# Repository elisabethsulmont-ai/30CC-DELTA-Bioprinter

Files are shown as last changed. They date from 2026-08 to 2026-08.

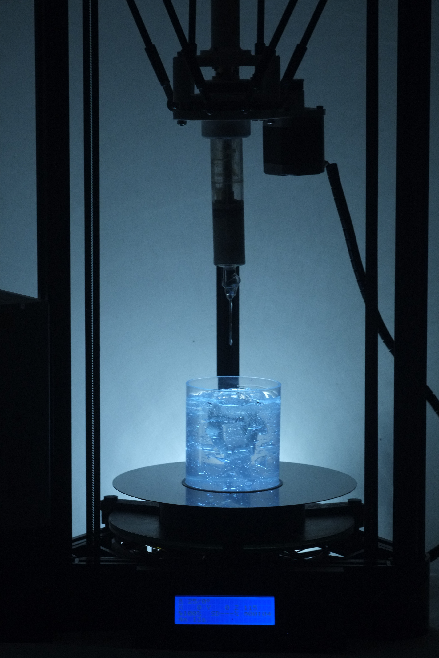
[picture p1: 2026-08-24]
5_PROJET EXAMPLES/DSCF0151.JPG

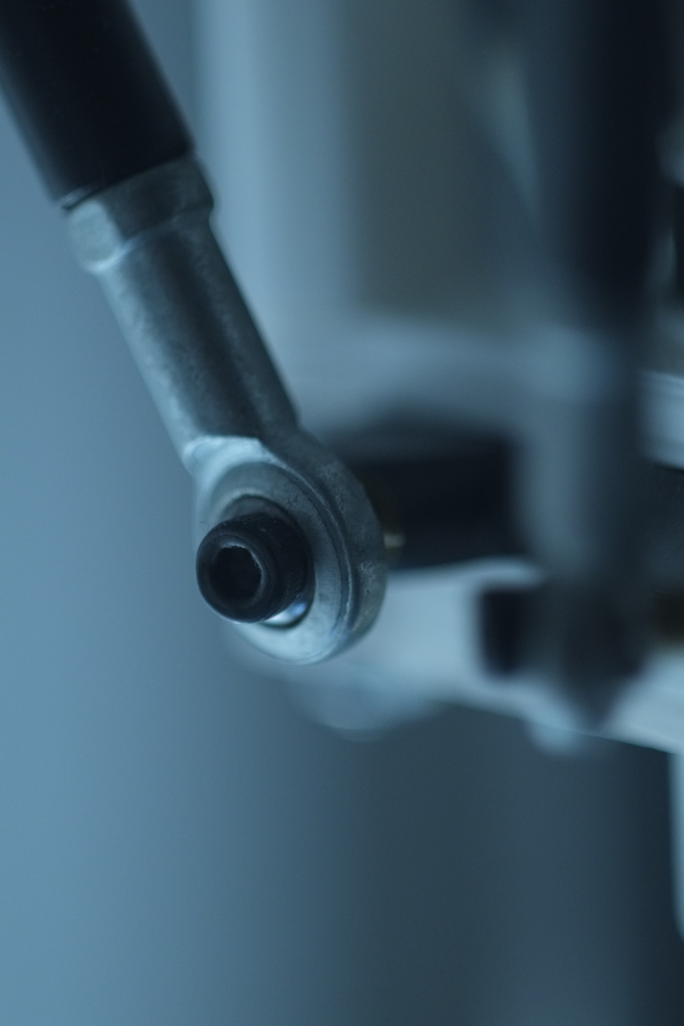
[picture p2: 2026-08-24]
5_PROJET EXAMPLES/DSCF0004.JPG

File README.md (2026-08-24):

# 30CC-DELTA-Bioprinter

An open source syringe bioprinter for the extrusion of viscous biomaterials, developed with
Ilias Poutsiakas ([github.com/iliasPts](https://github.com/iliasPts)).

It is built on an Anycubic Kossel Linear, stripped down to its bare frame and control board.
The hotend and its heating assembly are removed and replaced by a syringe extruder, designed
after the [300CC Extruder](https://www.thingiverse.com/thing:5215048) by Emmanuel Hugnot. The
stock firmware is replaced by an open source one: extrusion rates rescaled for a plunger
instead of a filament drive, travel limits redefined around the syringe, everything tied to
heating the nozzle removed.

The syringe is a 30 cc glass barrel with a metal luer lock, sized for fine biomaterials in
small volumes. Changing the tip is enough to set the flow, which matches the machine to the
viscosity of the material, down to very fluid ones. Tips run from 0.31 to 2.69 mm inner
diameter, 24G to 10G. The extrusion is cold.

A delta can be fed trajectories directly, without going through a conventional slicer: the
G-code can be a continuous path in space rather than a stack of planes. The motors are fixed
to the frame and no axis is privileged, so a curve costs the machine no more than a straight
line and the movement stays fluid. Conventional layer by layer printing works just as well.

The build is inexpensive and every part can be found in a hardware store. The concept is to
make bioprinting accessible outside of laboratories. What the machine makes depends on what
goes in the syringe and on what it prints into. Here it has been used for embedded printing
in a Carbopol support bath, and that method is documented in this repository.

**!!!!!!!!!!!!This is a workshop machine, made for experimental work. It is not a laboratory instrument, it is certified for nothing and it is not intended for any medical use.!!!!!!!!!!!!**

Other than than, Have fun <3

## What is in this repository

| Folder | What's inside |
|---|---|
| `3D files` | Parts to print, and the editable sources to modify them |
| `Components bill` | Everything to buy, with quantities and where to find it |
| `Assembly` | How to build it, step by step, with photos |
| `Firmware_marlin` | The two configuration files, and how to compile them |
| `Project examples` | Projects made with the machine, starting with Liquid Dreaming |

The order to follow: strip the printer down, print the parts from `3D files`, order what is
listed in `Components bill`, build it with `Assembly`, then flash the firmware from
`Firmware_marlin`. Once the machine runs, `Project examples` shows what has been done with it.

DSCF9794-3

DSCF9827-3

___________________________________

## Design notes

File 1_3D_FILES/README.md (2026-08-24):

## Materials

| Part | Material | Why |
|---|---|---|
| All parts | Matte white PLA | rigid enough, and easy to source anywhere |
| Piston | [TPU 95A HF](https://eu.store.bambulab.com/fr/products/tpu-95a-hf) | flexible, so it seals against the syringe wall |

The piston is the only part that is not printed rigid. A rigid piston does not seal: the
paste creeps back up along the barrel wall instead of coming out of the tip. Printed in TPU,
the piston deforms slightly against the glass and acts as its own gasket.

TPU prints slowly and does not tolerate retraction well. Print it with no retraction, at low
speed, and with a direct drive extruder if you have one.

<!-- TODO : tes réglages réels pour le piston. Le taux de remplissage et le nombre de parois
     comptent beaucoup ici, puisque c'est l'étanchéité qui est en jeu. -->

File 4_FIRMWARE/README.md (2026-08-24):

# Firmware

This machine runs a modified configuration of Marlin, on the knutwurst fork for Anycubic
Kossel printers. Only the two configuration files are published here. The firmware source
itself is not redistributed, since it is upstream work under GPL v3.

## Files

| File | What it is |
|---|---|
| `Configuration.h` | Machine geometry, board, extrusion, endstops |
| `Configuration_adv.h` | Advanced settings |

## How to build it

1. Download the upstream firmware:
   [knutwurst/Marlin-2-0-x-Anycubic-Kossel-Linear-Plus](https://github.com/knutwurst/Marlin-2-0-x-Anycubic-Kossel-Linear-Plus)
   The repository is named after the Plus, but it covers both machine sizes. The
   `KNUTWURST_KOSSEL_PLUS` option selects between them, and it is left disabled here.
2. Replace `Marlin/Configuration.h` and `Marlin/Configuration_adv.h` in that repository with
   the two files from this folder.
3. Compile and flash with PlatformIO.
4. After flashing, send these three commands in this order:

| Command | What it does |
|---|---|
| `M502` | Loads the settings compiled into the firmware, the ones from `Configuration.h`, into memory. It does not save them yet. |
| `M500` | Writes the settings currently in memory to the EEPROM, so they survive a power cycle. |
| `G28` | Homes the machine. On a delta all three carriages travel to the top endstops, which re-establishes the origin. |

The order matters. Marlin reads the EEPROM at startup, not the file you just compiled, so after
flashing the printer is still running on the values stored before. `M502` pulls in the new
ones, `M500` makes them permanent, `G28` gives the machine a valid origin to work from.

**This sequence erases anything set at runtime.** Values entered with `M92`, `M665`, `M666` or
produced by a `G33` auto calibration are overwritten by the ones in the file. Any calibration
has to be redone after this, then saved again with `M500`.

Full command reference: [marlinfw.org/meta/gcode](https://marlinfw.org/meta/gcode/)

## Bed and zero position

The original print bed is removed for this set up. Only the bare metal disc is kept underneath, which is a matter of
taste rather than a technical requirement.

The delta distances and the zero position are calculated from the surface of that disc, plus
30 mm. That margin exists so that the tip can never reach the disc and crash the syringe
assembly into it.

## Settings

| | |
|---|---|
| Base | Marlin 2.0.5, knutwurst Anycubic Kossel fork |
| Board | Trigorilla 1.4 |
| Machine | Anycubic Kossel, standard size, `KNUTWURST_KOSSEL_PLUS` disabled |
| Kinematics | Delta |
| Diagonal rod | 218 mm |
| Delta radius | 97 mm |
| Printable radius | 60 mm |
| Print height | 125 mm |
| Bed probe | None, manual levelling |
| Extruders | 1 |
| Hotend thermistor | Disabled, `TEMP_SENSOR_0 998` |
| Cold extrusion | Enabled, `EXTRUDE_MINTEMP 0` |
| E steps per mm | 96 |
| Max E feedrate | 1000 mm/s |
| Max E acceleration | 3000 mm/s² |

## What was changed, and why

| Setting | Stock | Here | Why |
|---|---|---|---|
| `TEMP_SENSOR_0` | thermistor | `998` | there is no hotend, the sensor is replaced by a dummy so the firmware does not fault |
| `EXTRUDE_MINTEMP` | 170 | `0` | paste is extruded cold, the firmware must stop refusing to move E |
| `DELTA_PRINTABLE_RADIUS` | <!-- valeur d'origine, à retrouver dans le dépôt de knutwurst --> | `60` | reduced to avoid collisions between the syringe assembly and the towers |
| `DELTA_HEIGHT` | <!-- valeur d'origine --> | `125` | <!-- à compléter --> |

## Known limitation

The E steps per mm are still the stock value for the printer's original filament extruder.
They have not been calibrated for the syringe drive, so the commanded extrusion length does
not correspond to a known volume. Calibrating this is the first thing to do on a new build.

<!-- Élisabeth : si tu as calibré, remplace ce paragraphe par la procédure et la valeur.
     Si tu ne l'as pas fait, laisse-le : c'est honnête, et ça évite qu'on prenne 96 pour une
     valeur mesurée. -->

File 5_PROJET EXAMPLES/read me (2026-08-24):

# Liquid Dreaming

The first project made with this machine, and the reason it was built.

<!-- photo d'ouverture : une impression en suspension dans le bain, prise à travers le gel -->

## The project

Liquid Dreaming is a methodological platform. Dream narratives are passed through the latent
space of a model, semantic trajectories are extracted from it, and those trajectories become
the geometry printed inside the gel. The dreams are not the point, they are the entry that
made sense.

This folder documents the printing side of the project: how the shapes get made physically.

## Why print inside a gel

Soft matter laid in open air can only build what gravity allows. It slumps, it spreads, it
falls. Printing into a support bath removes that limit.

The bath used here is a Carbopol gel. It is transparent and self-healing: it opens ahead of
the needle and closes behind it. What is deposited stays where it was deposited, held in
suspension for the length of the print. Shapes that could not stand on their own become
printable.

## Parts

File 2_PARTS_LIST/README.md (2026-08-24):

# Components bill

Everything needed to build one machine, on top of an Anycubic Kossel.
Printed parts are not listed here, they are in the 3D files folder.

Only three parts need to be sourced specifically. Everything else is standard and available
in any hardware store.

## Sourced parts

| Ref | Part | Spec | Qty | Where |
|---|---|---|---|---|
| F-01 | Glass syringe | 30 ml, metal luer lock | 1 | [Amazon](https://www.amazon.fr/dp/B0B42BKT3S) |
| F-02 | Blunt dispensing needles | Stainless steel, luer lock, 1.5 in, 10G to 24G, 16 pcs | 1 set | [Amazon](https://www.amazon.fr/dp/B083FCSTTY) |
| D-02 | Timing belt | GT2, 6 mm wide, 2 mm pitch, 224 mm | 2 | [Amazon](https://www.amazon.fr/dp/B07NDYF2BT) |

## From the hardware store

| Ref | Part | Spec | Qty |
|---|---|---|---|
| D-01 | Lead screw | T8, 220 mm, pitch 2 mm, lead 4 mm | 1 |
| D-03 | Bearing | inner 12 mm, outer 21 mm | 1 set |
| V-01 | Grub screw | M3 x 6, headless | 2 |
| V-02 | Screw | M3 x 10 | 7 |
| V-03 | Screw | M3 x 12 | 4 |
| V-04 | Screw | M3 x 16 | 4 |
| V-05 | Screw | M3 x 18 | 4 |
| V-06 | Screw | M4 x 32 | 3 |
| V-07 | Washer | M3 | 1 set |
| V-08 | Washer | M4 | 3 |
| V-09 | Washer | 12 mm | 1 set |
| V-10 | Nut | M3 | 1 set |
| V-11 | Nut | M4 | 1 set |

## Not bought

The stepper motor is the printer's original extruder motor.
The 26T and 60T pulleys are printed, see the 3D files folder.

## Starting point

The parts list of Emmanuel Hugnot's [300CC Extruder](https://www.thingiverse.com/thing:5215048)
is a good skeleton and it is already online. Start from it, and note for each line whether the
part was kept, changed or dropped.

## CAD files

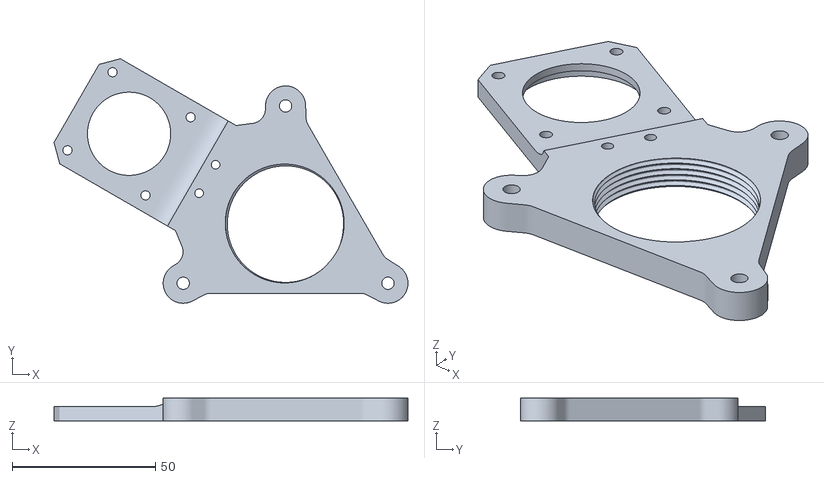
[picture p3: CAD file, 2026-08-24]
1_3D_FILES/main_plate.stl
123.4 x 85.3 x 8.00

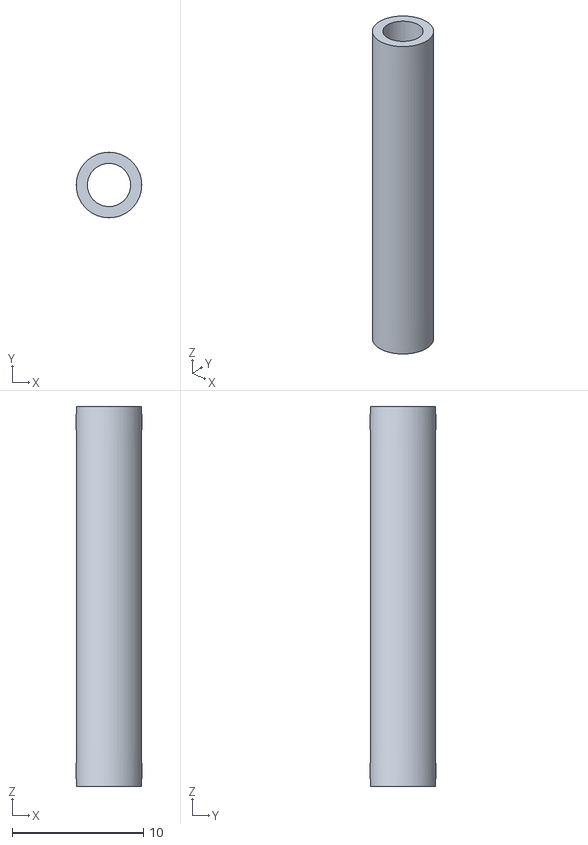
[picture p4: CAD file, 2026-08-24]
1_3D_FILES/spacer.stl
5.00 x 5.00 x 29.0

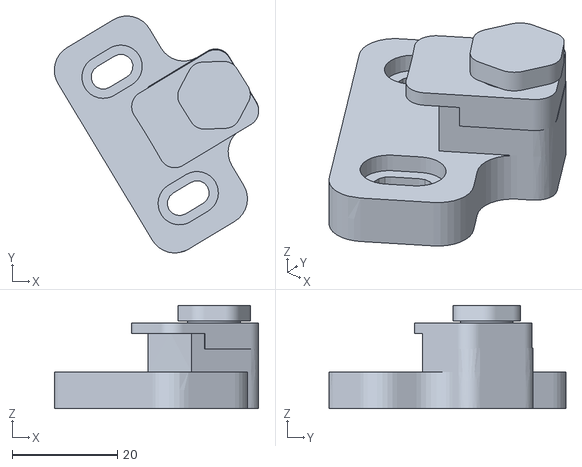
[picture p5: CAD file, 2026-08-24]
1_3D_FILES/plate_clips.stl
38.9 x 45.1 x 19.6

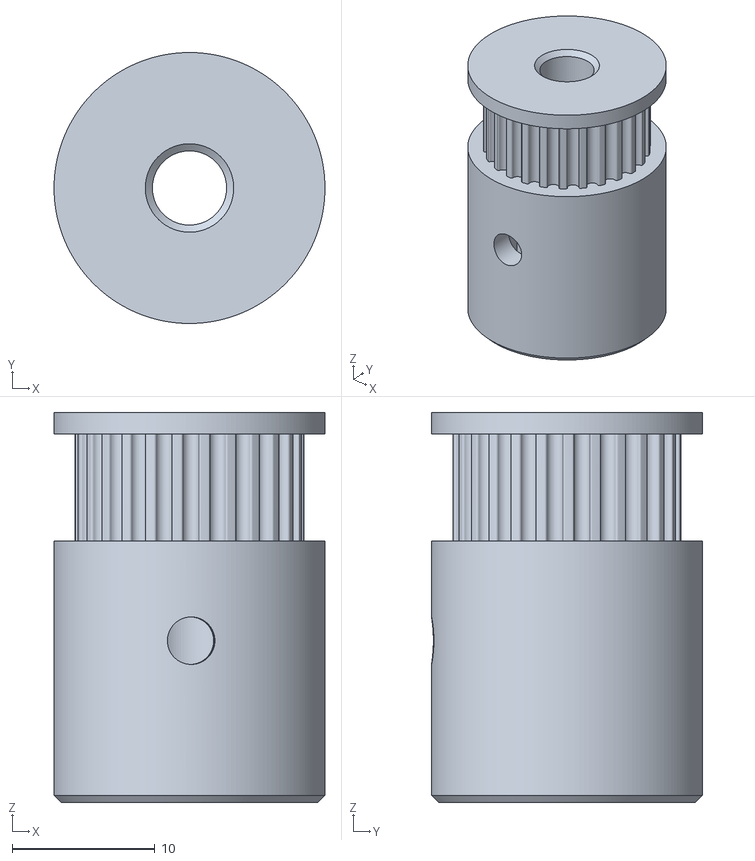
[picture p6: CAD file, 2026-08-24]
1_3D_FILES/GT2_pulley_26T.stl
19.0 x 19.0 x 27.3

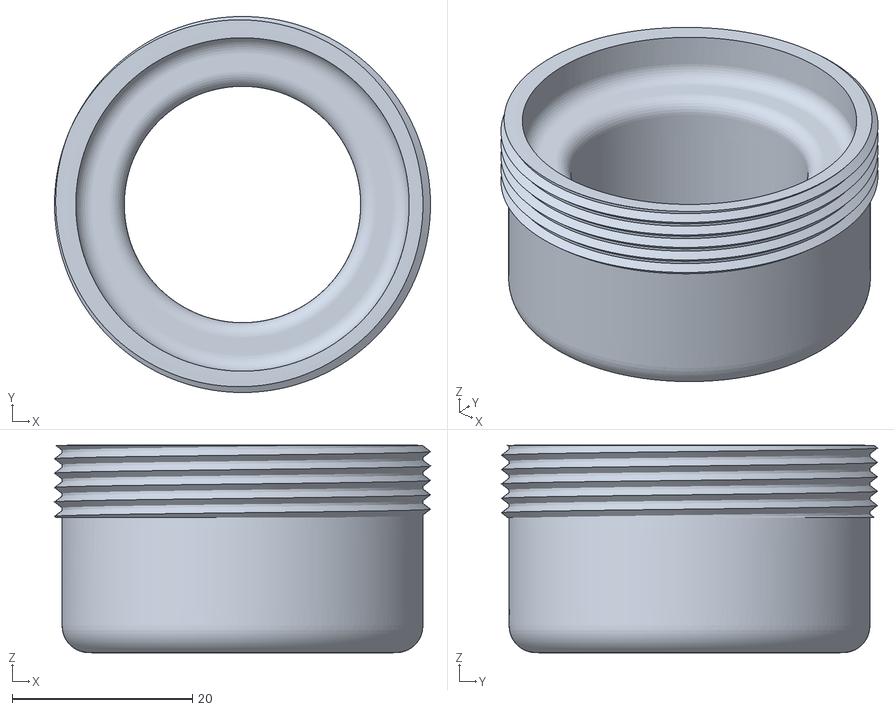
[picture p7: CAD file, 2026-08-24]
1_3D_FILES/seringue_locker.stl
41.7 x 41.7 x 23.0

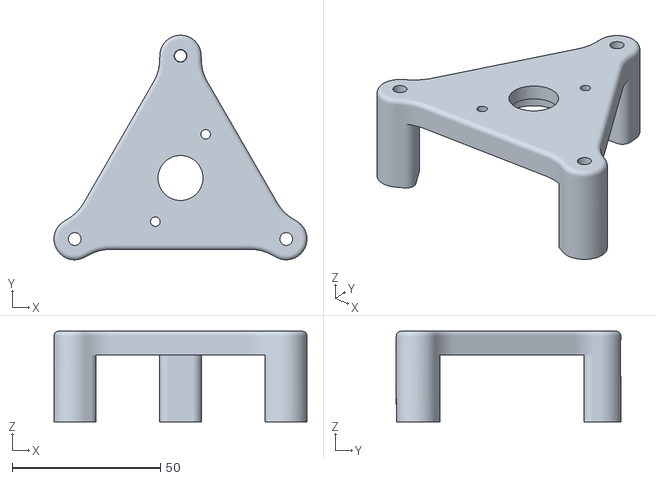
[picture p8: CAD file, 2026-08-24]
1_3D_FILES/top_plate.stl
85.4 x 75.8 x 30.6

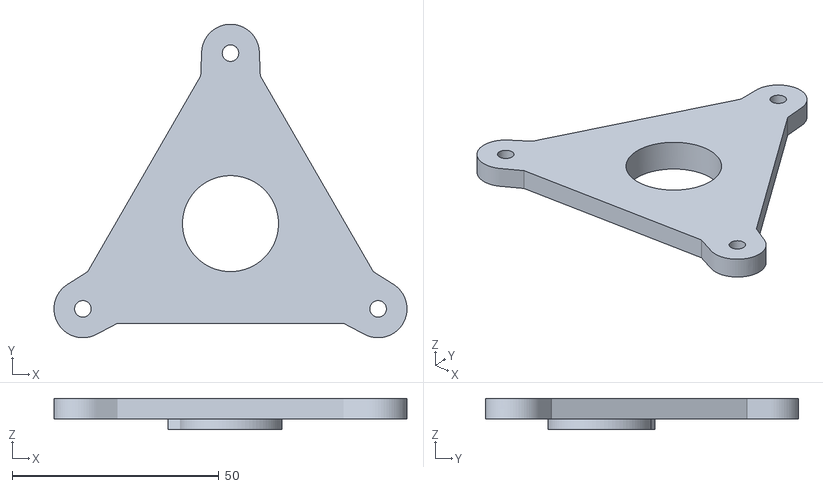
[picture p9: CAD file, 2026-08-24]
1_3D_FILES/secondary_plate.stl
85.3 x 75.8 x 7.50

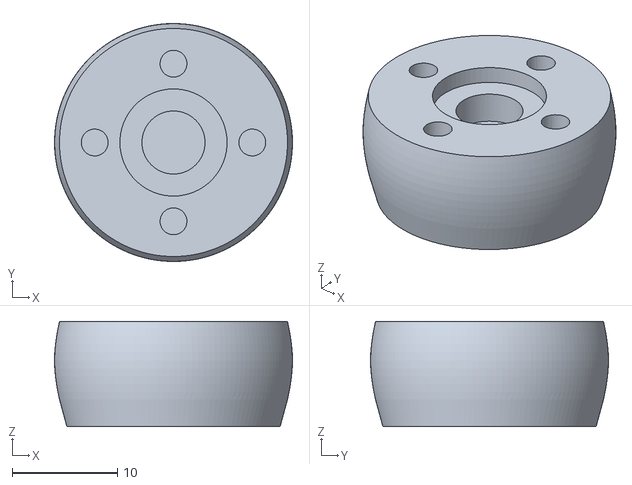
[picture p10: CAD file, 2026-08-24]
1_3D_FILES/piston.stl
22.6 x 22.6 x 10.0

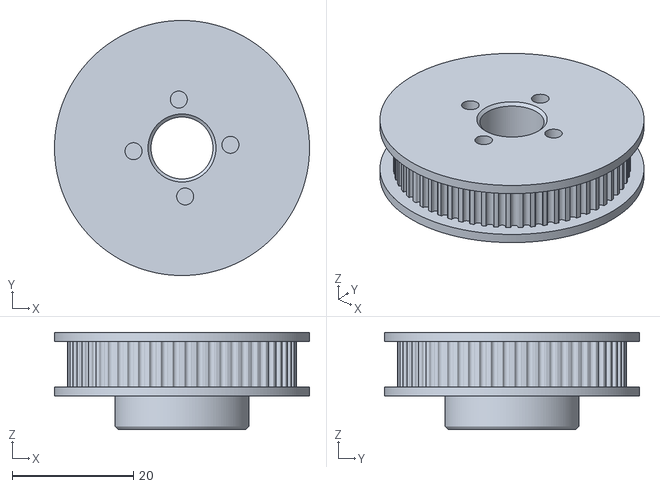
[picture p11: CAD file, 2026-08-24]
1_3D_FILES/GT2_pulley_60T.stl
42.0 x 42.0 x 16.0

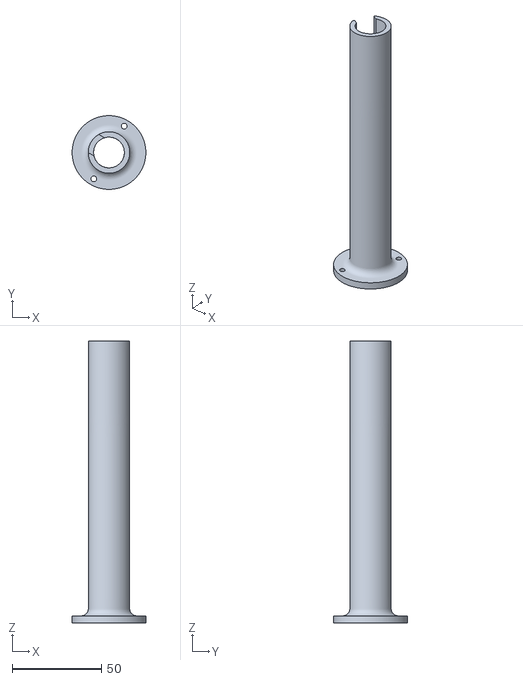
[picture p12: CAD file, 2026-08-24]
1_3D_FILES/leadscrew_housing.stl
41.2 x 41.2 x 157.6

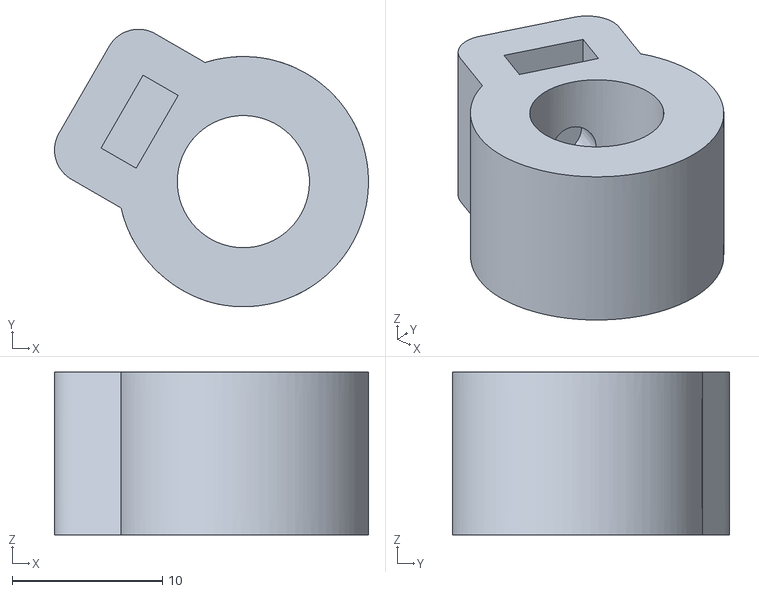
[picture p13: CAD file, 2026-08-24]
1_3D_FILES/leadscrew_mount.stl
20.9 x 18.5 x 10.8

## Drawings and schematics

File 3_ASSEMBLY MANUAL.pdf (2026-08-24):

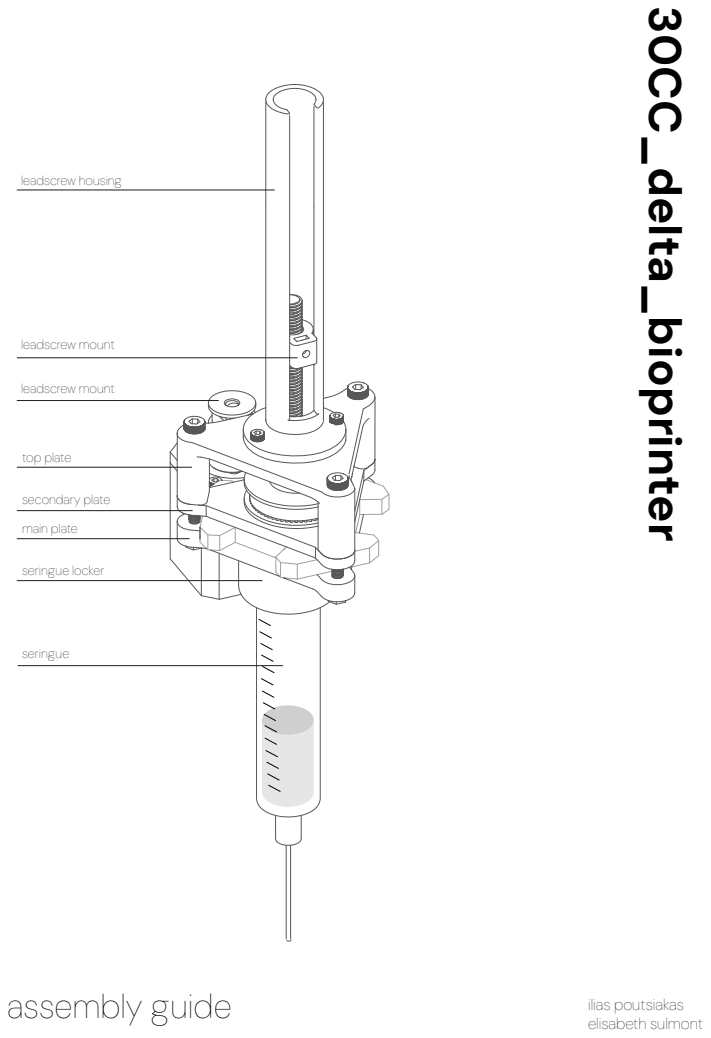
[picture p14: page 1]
assembly guide; ilias poutsiakas; elisabeth sulmont; leadscrew housing; leadscrew mount; top plate; secondary plate; main plate; seringue locker; seringue; 30CC_delta_bioprinter

# step 1

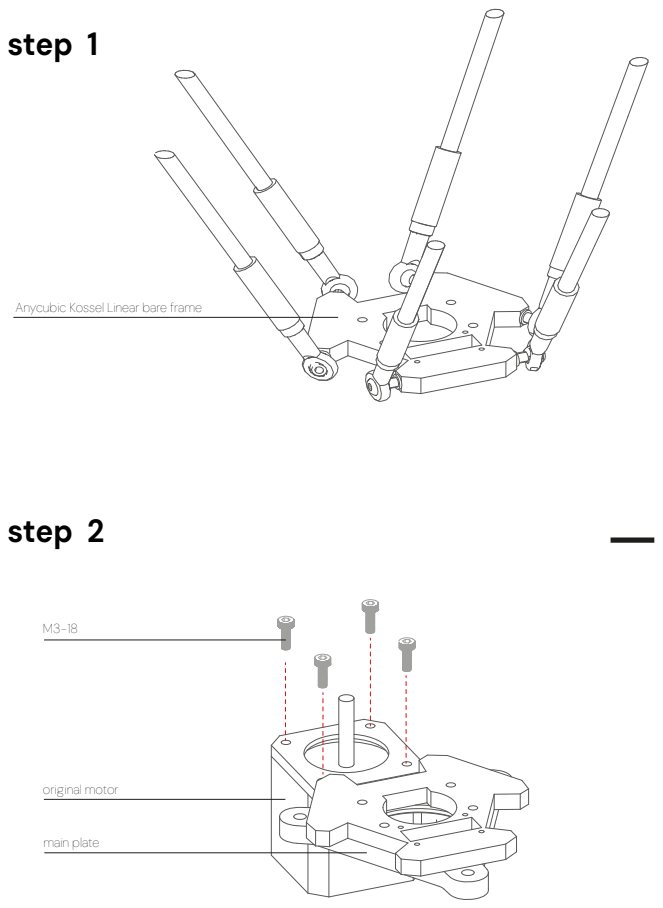
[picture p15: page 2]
original motor; main plate; step 2

Anycubic Kossel Linear bare frame

# step 3

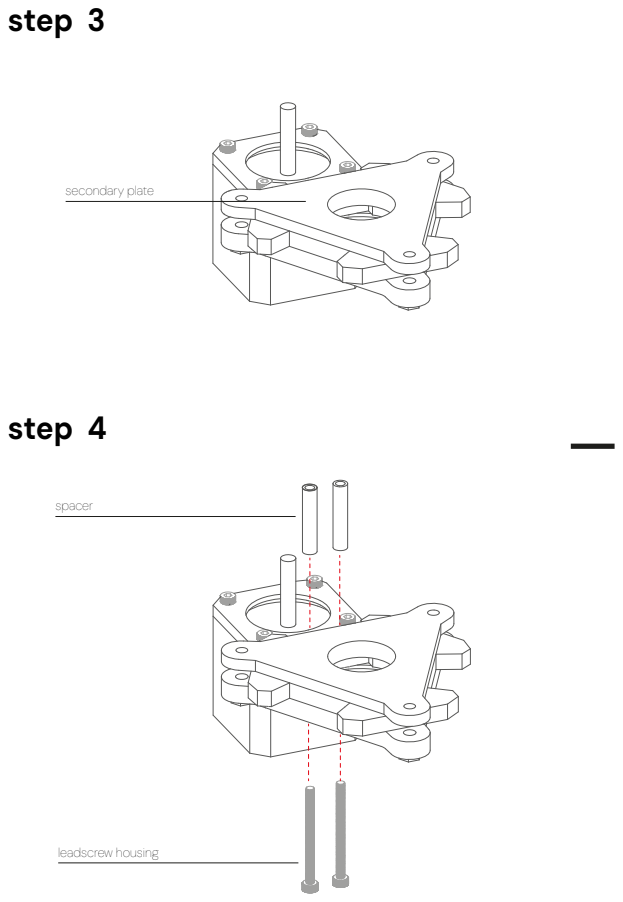
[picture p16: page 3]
secondary plate; leadscrew housing; spacer; step 4

# step 5

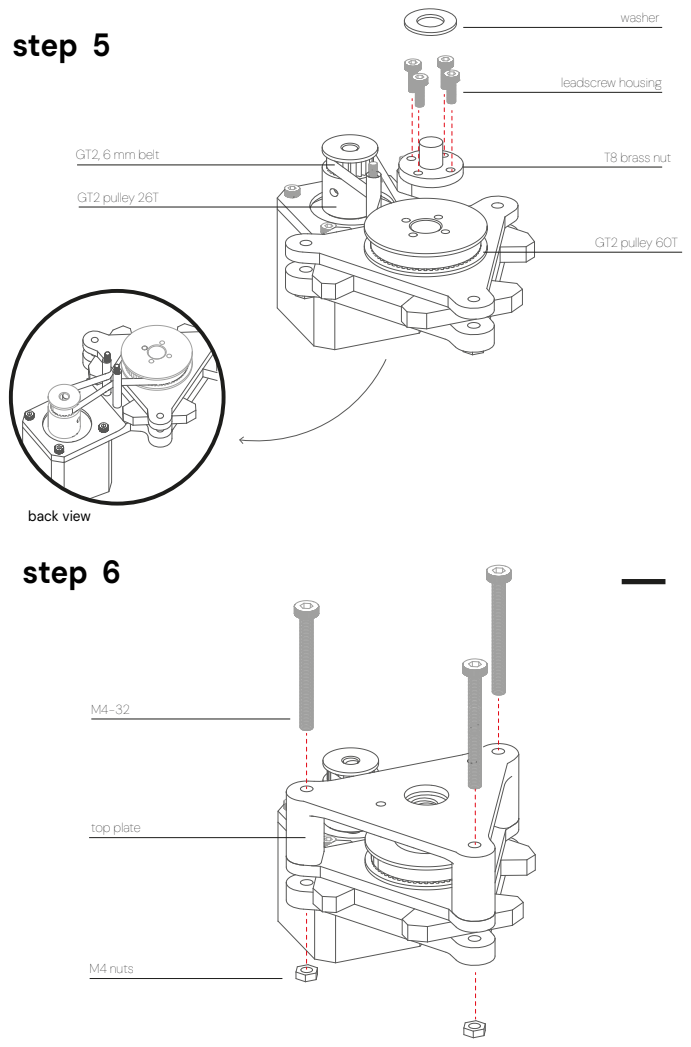
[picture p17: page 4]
leadscrew housing; T8 brass nut; washer; GT2 pulley 60T; top plate; M4 nuts; GT2 pulley 26T; GT2, 6 mm belt; back view step 6

# step 7

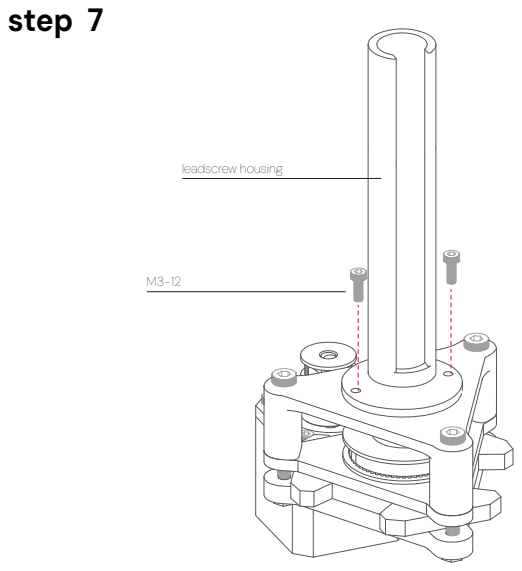
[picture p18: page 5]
leadscrew housing

# step 8

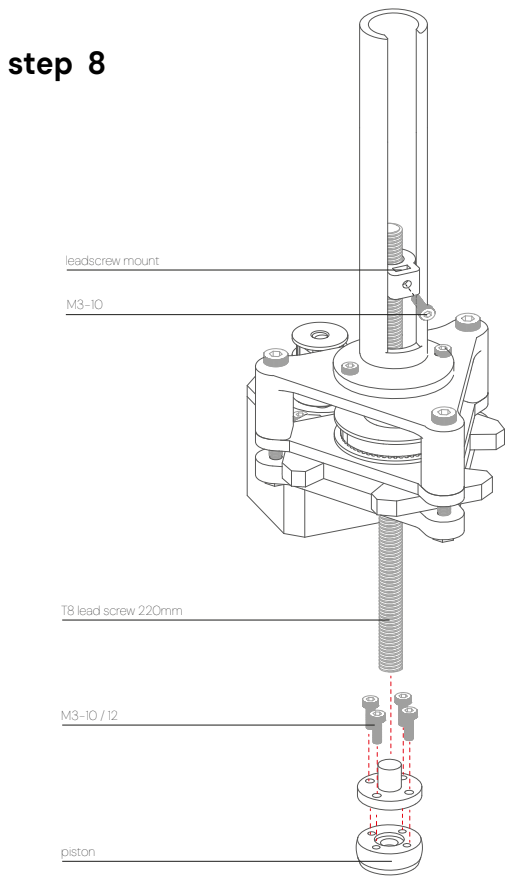
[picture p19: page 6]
leadscrew mount; piston; T8 lead screw 220mm

# step 9

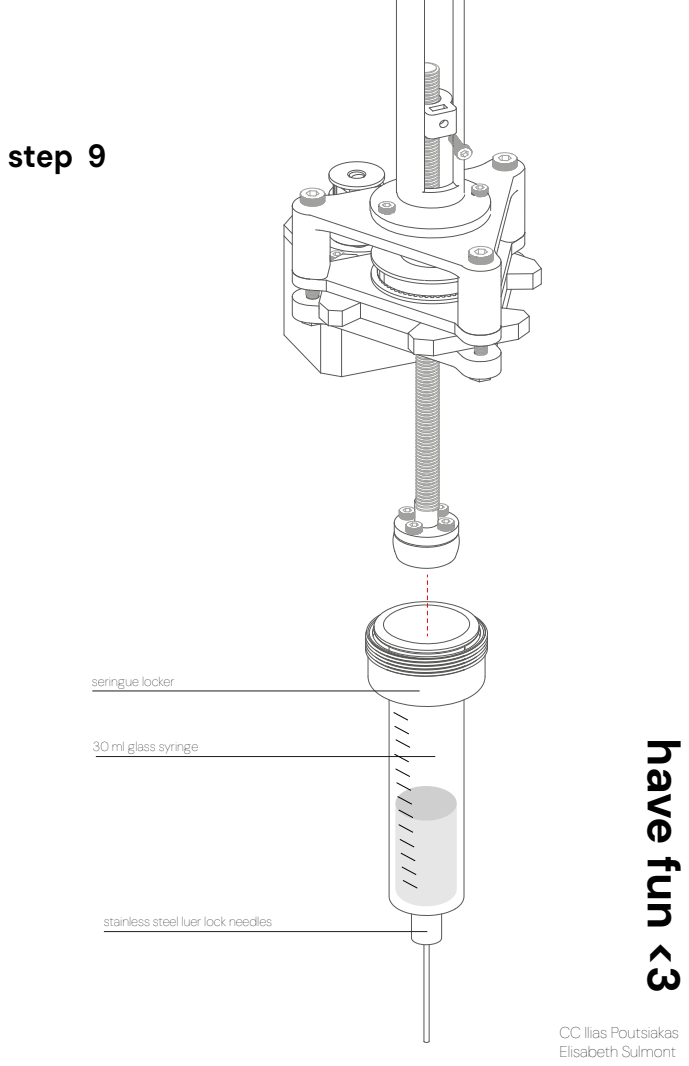
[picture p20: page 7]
seringue locker; have fun <3

30 ml glass syringe

stainless steel luer lock needles

CC Ilias Poutsiakas
Elisabeth Sulmont

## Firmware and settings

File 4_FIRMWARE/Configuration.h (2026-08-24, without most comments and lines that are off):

#pragma once
    #define ANYCUBIC_PROBE_VERSION 0
   #define KNUTWURST_KOSSEL_ENABLE_BED 0
#define CONFIGURATION_H_VERSION 020005
#define STRING_CONFIG_H_AUTHOR "@knutwurst" // Who made the changes.
#define SHOW_BOOTSCREEN
#define SERIAL_PORT 0
#define BAUDRATE 250000
  #define MOTHERBOARD BOARD_TRIGORILLA_14
#define CUSTOM_MACHINE_NAME "FRESH Delta custom printer"
#define EXTRUDERS 1
#define DEFAULT_NOMINAL_FILAMENT_DIA 1.75
#define TEMP_SENSOR_0 998
#define TEMP_SENSOR_1 0
#define TEMP_SENSOR_2 0
#define TEMP_SENSOR_3 0
#define TEMP_SENSOR_4 0
#define TEMP_SENSOR_5 0
#if KNUTWURST_KOSSEL_ENABLE_BED > 0
   #define TEMP_SENSOR_BED 5
#else
  #define TEMP_SENSOR_BED 0
#endif
#define TEMP_SENSOR_CHAMBER 0
#define DUMMY_THERMISTOR_998_VALUE 25
#define DUMMY_THERMISTOR_999_VALUE 100
#define MAX_REDUNDANT_TEMP_SENSOR_DIFF 10
#define TEMP_RESIDENCY_TIME     10  // (seconds) Time to wait for hotend to "settle" in M109
#define TEMP_WINDOW              1  // (°C) Temperature proximity for the "temperature reached" timer
#define TEMP_HYSTERESIS          3  // (°C) Temperature proximity considered "close enough" to the target
#define TEMP_BED_RESIDENCY_TIME 10  // (seconds) Time to wait for bed to "settle" in M190
#define TEMP_BED_WINDOW          1  // (°C) Temperature proximity for the "temperature reached" timer
#define TEMP_BED_HYSTERESIS      3  // (°C) Temperature proximity considered "close enough" to the target
#define HEATER_0_MINTEMP   5
#define HEATER_1_MINTEMP   5
#define HEATER_2_MINTEMP   5
#define HEATER_3_MINTEMP   5
#define HEATER_4_MINTEMP   5
#define HEATER_5_MINTEMP   5
#define HEATER_6_MINTEMP   5
#define HEATER_7_MINTEMP   5
#define BED_MINTEMP        5
#define HEATER_0_MAXTEMP 275
#define HEATER_1_MAXTEMP 275
#define HEATER_2_MAXTEMP 275
#define HEATER_3_MAXTEMP 275
#define HEATER_4_MAXTEMP 275
#define HEATER_5_MAXTEMP 275
#define HEATER_6_MAXTEMP 275
#define HEATER_7_MAXTEMP 275
#define BED_MAXTEMP      150
#define BANG_MAX 255     // Limits current to nozzle while in bang-bang mode; 255=full current
#define PID_MAX BANG_MAX // Limits current to nozzle while PID is active (see PID_FUNCTIONAL_RANGE below); 255=full current
#define PID_K1 0.95      // Smoothing factor within any PID loop
#if KNUTWURST_KOSSEL_ENABLE_BED > 0
  #define PIDTEMPBED
#endif
#define MAX_BED_POWER 255 // limits duty cycle to bed; 255=full current
#if ENABLED(PIDTEMPBED)
  #if KNUTWURST_KOSSEL_ENABLE_BED == 1
    #define DEFAULT_bedKp 374.03
    #define DEFAULT_bedKi 72.47
    #define DEFAULT_bedKd 482.59
  #elif KNUTWURST_KOSSEL_ENABLE_BED == 2
    #define DEFAULT_bedKp 251.78
    #define DEFAULT_bedKi 49.57
    #define DEFAULT_bedKd 319.73
  #endif
#endif // PIDTEMPBED
#define EXTRUDE_MINTEMP 0
#define PREVENT_LENGTHY_EXTRUDE
#define EXTRUDE_MAXLENGTH 750
#if KNUTWURST_KOSSEL_ENABLE_BED > 0
    #define THERMAL_PROTECTION_BED     // Enable thermal protection for the heated bed
#endif
#define THERMAL_PROTECTION_CHAMBER // Enable thermal protection for the heated chamber
#define DELTA
  #define DELTA_SEGMENTS_PER_SECOND 80
  #define DELTA_CALIBRATION_MENU
  #if ANYCUBIC_PROBE_VERSION > 0 || ENABLED(KNUTWURST_BLTOUCH)
    #define DELTA_AUTO_CALIBRATION
  #endif
  #if ENABLED(DELTA_AUTO_CALIBRATION)
    #define DELTA_CALIBRATION_DEFAULT_POINTS 4
  #endif
  #if EITHER(DELTA_AUTO_CALIBRATION, DELTA_CALIBRATION_MENU)
    #define PROBE_MANUALLY_STEP 0.05      // (mm)
  #endif
    #define DELTA_PRINTABLE_RADIUS 60   // (mm)
    #define DELTA_DIAGONAL_ROD 218.0      // (mm)
    #define DELTA_RADIUS 97.0             // (mm) Get this value from G33 auto calibrate
  #define DELTA_HEIGHT 125.00             // (mm) Get this value from G33 auto calibrate
  #define DELTA_ENDSTOP_ADJ { 0.0, 0.0, 0.0 } // Get these values from G33 auto calibrate
  #define DELTA_TOWER_ANGLE_TRIM { 0.0, 0.0, 0.0 } // Get these values from G33 auto calibrate
#if ANYCUBIC_PROBE_VERSION > 0 || ENABLED(KNUTWURST_BLTOUCH)
  #define USE_ZMIN_PLUG // a Z probe
#endif
#define USE_XMAX_PLUG
#define USE_YMAX_PLUG
#define USE_ZMAX_PLUG
#define ENDSTOPPULLUPS
#define X_MIN_ENDSTOP_INVERTING false  // Set to true to invert the logic of the endstop.
#define Y_MIN_ENDSTOP_INVERTING false  // Set to true to invert the logic of the endstop.
#define Z_MIN_ENDSTOP_INVERTING (ANYCUBIC_PROBE_VERSION + 0 == 1) // V1 is NO, V2 is NC
#define X_MAX_ENDSTOP_INVERTING false  // Set to true to invert the logic of the endstop.
#define Y_MAX_ENDSTOP_INVERTING false  // Set to true to invert the logic of the endstop.
#define Z_MAX_ENDSTOP_INVERTING false  // Set to true to invert the logic of the endstop.
#define Z_MIN_PROBE_ENDSTOP_INVERTING Z_MIN_ENDSTOP_INVERTING
    #define X_DRIVER_TYPE  A4988
    #define Y_DRIVER_TYPE  A4988
    #define Z_DRIVER_TYPE  A4988
    #define E0_DRIVER_TYPE A4988
#define ENDSTOP_NOISE_THRESHOLD 2
#define XYZ_FULL_STEPS_PER_ROTATION 200
#define XYZ_MICROSTEPS 16
#define XYZ_BELT_PITCH 2
#define XYZ_PULLEY_TEETH 20
#define DEFAULT_XYZ_STEPS_PER_UNIT ((XYZ_FULL_STEPS_PER_ROTATION) * (XYZ_MICROSTEPS) / double(XYZ_BELT_PITCH) / double(XYZ_PULLEY_TEETH)) // 80
#define DEFAULT_AXIS_STEPS_PER_UNIT   { DEFAULT_XYZ_STEPS_PER_UNIT, DEFAULT_XYZ_STEPS_PER_UNIT, DEFAULT_XYZ_STEPS_PER_UNIT, 96 }  // default steps per unit for Kossel (GT2, 20 tooth)
#define DEFAULT_MAX_FEEDRATE          { 100, 100, 100, 1000}
#define DEFAULT_MAX_ACCELERATION       { 3000, 3000, 3000, 3000 }
#define DEFAULT_ACCELERATION          3000    // X, Y, Z and E acceleration for printing moves
#define DEFAULT_RETRACT_ACCELERATION  3000    // E acceleration for retracts
#define DEFAULT_TRAVEL_ACCELERATION   1500    // X, Y, Z acceleration for travel (non printing) moves
#define CLASSIC_JERK
  #define DEFAULT_XJERK  5.0
  #define DEFAULT_YJERK  DEFAULT_XJERK
  #define DEFAULT_ZJERK  DEFAULT_XJERK // Must be same as XY for delta
#define DEFAULT_EJERK    5.0  // May be used by Linear Advance
#define S_CURVE_ACCELERATION
#if ANYCUBIC_PROBE_VERSION > 0 || ENABLED(KNUTWURST_BLTOUCH)
  #define Z_MIN_PROBE_USES_Z_MIN_ENDSTOP_PIN
#endif
#if ANYCUBIC_PROBE_VERSION == 0
      #define PROBE_MANUALLY
      #define MANUAL_PROBE_START_Z 1.5
#endif
#if ANYCUBIC_PROBE_VERSION > 0
  #define FIX_MOUNTED_PROBE
#endif
#if ENABLED(Z_PROBE_ALLEN_KEY)
  #define Z_PROBE_ALLEN_KEY_DEPLOY_1 { 30.0, DELTA_PRINTABLE_RADIUS, 100.0 }
  #define Z_PROBE_ALLEN_KEY_DEPLOY_1_FEEDRATE XY_PROBE_SPEED
  #define Z_PROBE_ALLEN_KEY_DEPLOY_2 { 0.0, DELTA_PRINTABLE_RADIUS, 100.0 }
  #define Z_PROBE_ALLEN_KEY_DEPLOY_2_FEEDRATE (XY_PROBE_SPEED)/10
  #define Z_PROBE_ALLEN_KEY_DEPLOY_3 { 0.0, (DELTA_PRINTABLE_RADIUS) * 0.75, 100.0 }
  #define Z_PROBE_ALLEN_KEY_DEPLOY_3_FEEDRATE XY_PROBE_SPEED
  #define Z_PROBE_ALLEN_KEY_STOW_1 { -64.0, 56.0, 23.0 } // Move the probe into position
  #define Z_PROBE_ALLEN_KEY_STOW_1_FEEDRATE XY_PROBE_SPEED
  #define Z_PROBE_ALLEN_KEY_STOW_2 { -64.0, 56.0, 3.0 } // Push it down
  #define Z_PROBE_ALLEN_KEY_STOW_2_FEEDRATE (XY_PROBE_SPEED)/10
  #define Z_PROBE_ALLEN_KEY_STOW_3 { -64.0, 56.0, 50.0 } // Move it up to clear
  #define Z_PROBE_ALLEN_KEY_STOW_3_FEEDRATE XY_PROBE_SPEED
  #define Z_PROBE_ALLEN_KEY_STOW_4 { 0.0, 0.0, 50.0 }
  #define Z_PROBE_ALLEN_KEY_STOW_4_FEEDRATE XY_PROBE_SPEED
#endif // Z_PROBE_ALLEN_KEY
#if ANYCUBIC_PROBE_VERSION == 2
  #define NOZZLE_TO_PROBE_OFFSET { 0, 0, -150 } //Offset for Probe until it clicks. So no need for paper leveling anymore!
#elif ANYCUBIC_PROBE_VERSION == 1
  #define NOZZLE_TO_PROBE_OFFSET { 0, 0, -19.0 }
#else
      #define NOZZLE_TO_PROBE_OFFSET { 10, 10, 0 }
#endif
#define MIN_PROBE_EDGE 30
#define XY_PROBE_SPEED 1000
#define Z_PROBE_SPEED_FAST HOMING_FEEDRATE_Z
#define Z_PROBE_SPEED_SLOW (Z_PROBE_SPEED_FAST / 3)
#define Z_CLEARANCE_DEPLOY_PROBE   50 // Z Clearance for Deploy/Stow
#define Z_CLEARANCE_BETWEEN_PROBES 5 // Z Clearance between probe points
#define Z_CLEARANCE_MULTI_PROBE    5 // Z Clearance between multiple probes
    #define Z_PROBE_LOW_POINT          -2 // Farthest distance below the trigger-point to go before stopping
#define Z_PROBE_OFFSET_RANGE_MIN -40
#define Z_PROBE_OFFSET_RANGE_MAX 20
#if ANYCUBIC_PROBE_VERSION > 0 || ENABLED(KNUTWURST_BLTOUCH)
  #define Z_MIN_PROBE_REPEATABILITY_TEST
#endif
#define PAUSE_BEFORE_DEPLOY_STOW
#define X_ENABLE_ON 0
#define Y_ENABLE_ON 0
#define Z_ENABLE_ON 0
#define E_ENABLE_ON 0 // For all extruders
#define DISABLE_X false
#define DISABLE_Y false
#define DISABLE_Z false
#define DISABLE_E false             // For all extruders
#define DISABLE_INACTIVE_EXTRUDER   // Keep only the active extruder enabled
    #define INVERT_X_DIR true
    #define INVERT_Y_DIR true
    #define INVERT_Z_DIR true
    #define INVERT_E0_DIR true
    #define INVERT_E1_DIR false
    #define INVERT_E2_DIR false
    #define INVERT_E3_DIR false
    #define INVERT_E4_DIR false
    #define INVERT_E5_DIR false
    #define INVERT_E6_DIR false
    #define INVERT_E7_DIR false
#define X_HOME_DIR 1  // deltas always home to max
#define Y_HOME_DIR 1
#define Z_HOME_DIR 1
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

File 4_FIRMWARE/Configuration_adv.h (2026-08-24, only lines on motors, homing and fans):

#define E0_AUTO_FAN_PIN -1 // turn of extruder fan when it's temperature is above 50°C
#define E1_AUTO_FAN_PIN -1
#define E2_AUTO_FAN_PIN -1
#define E3_AUTO_FAN_PIN -1
#define E4_AUTO_FAN_PIN -1
#define E5_AUTO_FAN_PIN -1
#define CHAMBER_AUTO_FAN_PIN -1
#define X_HOME_BUMP_MM 3
#define Y_HOME_BUMP_MM 3
#define Z_HOME_BUMP_MM 3 // deltas need the same for all three axes
#define HOMING_BUMP_DIVISOR { 2, 2, 2 }  // Re-Bump Speed Divisor (Divides the Homing Feedrate)
#define HOMING_BACKOFF_MM { 10, 10, 10 }  // (mm) Move away from the endstops after homing
#define HOME_AFTER_DEACTIVATE  // Require rehoming after steppers are deactivated
#define MICROSTEP_MODES { 16, 16, 16, 16, 16, 16 } // [1,2,4,8,16]
#define DIGIPOT_I2C_MOTOR_CURRENTS { 1.0, 1.0, 1.0, 1.0, 1.0, 1.0, 1.0, 1.0 }  //  AZTEEG_X3_PRO

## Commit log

2026-08-24 Refine README.md content and add external link
    Updated text for clarity and added a link to the 300CC Extruder.
2026-08-24 Create readme for Liquid Dreaming project
    Added documentation for the Liquid Dreaming project, detailing its methodology and printing process.
2026-08-24 Update README with tip diameter details
    Added information about tip diameters for the syringe extruder.
2026-08-24 Update README with syringe specifications and warnings
    Added details about the syringe specifications and usage warnings.

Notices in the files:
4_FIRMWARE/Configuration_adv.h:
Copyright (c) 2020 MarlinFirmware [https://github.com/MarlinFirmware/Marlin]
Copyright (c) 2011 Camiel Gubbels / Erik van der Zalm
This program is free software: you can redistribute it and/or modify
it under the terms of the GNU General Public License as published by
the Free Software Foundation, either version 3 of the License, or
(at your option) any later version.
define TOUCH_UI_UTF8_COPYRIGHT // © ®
